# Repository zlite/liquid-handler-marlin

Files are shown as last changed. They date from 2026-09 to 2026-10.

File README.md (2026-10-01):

There have been [many attempts](https://www.hardware-x.com/article/S2468-0672(26)00087-8/fulltext) to modify a cheap Ender 3 printer into a liquid handler using standard syringes, but most suffer from similar problems: too expensive (they often use parts purchased from approved academic vendors, which tend to be way more expensive than their Amazon equivalents), too big, too heavy, too complicated or too imprecise (for example, having no limit switches to accurately home the syringe). 

This is a modern version that improves on all of those dimensions along with adding a useful and easy to use web interface.

Advantages:
- Cheap: less than $250 INCLUDING the computer to control it
- Very precise: it should be good for +/- 10 microliters, repeatably
- Fully automatable via a Web API
- Easy to teach it new tasks, no coding required

BOM:
- Ender 3
- M5Stack Basic
- M5Stack USB module
- Pancake Stepper Motor
- 100m 5m lead screw
- 5mm to 5mm coupler
- 100m MG9 linear rail
- Limit switch
- 100 nf ceramic capaciter

Instructions. When assembling the Ender 3, skip the extruder and filament drive. Although you can re-purpose the stepper motor for our syringe drive, it's a hassle to remove the drive gear and it's bigger and heavier than we need, so I prefer to replace it with the smaller pancake stepper linked above.

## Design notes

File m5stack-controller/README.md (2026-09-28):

# 96-well teaching controller

M5Stack Core Basic + USB Module V1.2 + Ender Liquid Handler R5.
The controller provides a browser page for homing, incremental XYZ jogging,
and recording a standard 8 × 12, 9 mm pitch plate and reservoir.
It does not move automatically at boot. Dry runs leave the syringe stationary;
Home All and the explicit A diagnostics can home/move the syringe.

## Hardware and connection

USB Module switches: SS G5 ON, G0/G13 OFF; INT G35 ON, G34 OFF.
The CH340 Ender adapter (1a86:7523) runs at 250000 baud.
The controller uses USB Host Shield 2.0 with a custom CH340 driver.
Read one endpoint-sized packet at a time: larger reads can receive data then
return NAK without committing the data toggle, losing replies.

At connection, numbered/checksummed commands check firmware identification,
ten complete M114 replies, and acknowledged M400/M84. Motion controls remain
disabled until this passes. No timed-out movement is automatically replayed.
USB reconnect runs the checks again and invalidates session homing.

Open http://dispenser.local or the IP address displayed on the Core.
The network hostname is `dispenser`. The Core screen shows the current task,
connection state, IP address, session homing, last reported XYZ position, and
A limit switch (green **OPEN**, red **TRIGGERED**, yellow **UNKNOWN** when
stale or unavailable). Background switch polling does not replace task status.
It polls `M119` every 200 ms while the command queue is idle. These are
read-only queries and do not move or energize motors. Polling pauses behind
other operations; Marlin cannot service these queries during blocking homing.
Readings expire after one second, and polling can miss shorter pulses.
Use **Read limit switches** in the connection log to query `M119` without
moving. The syringe A-axis switch appears as `a_min`; the diagnostic finishes
with acknowledged motor release.
The web connection section also provides **Read motion settings** (`M503`)
and **Run A-only homing test**. The latter uses `G28 A R0` so XYZ stay put,
records switch/position reports before and after, and ends in `M400`/`M84`.
It requires a fresh OPEN switch reading. Its separate diagnostic log is at
`/api/a-homing-trace` and survives background polling (but not M5 restarts).
These standard G-code diagnostics do not capture brief triggers during homing.
The diagnostic API action `move_a_down_5` makes one 5 mm relative A move toward
home at 1 mm/s using the measured 1600 steps/mm. Because failed homing leaves
an untrustworthy A zero, this test temporarily disables software endstops;
`M120` keeps physical endstops enabled. It restores absolute mode and software
endstops, reports position/switches, and ends with `M400`/`M84`. Run only while
observing clear syringe travel. Physical endstops remain enabled afterward.
The diagnostic API action `hold_a_test` enables all drivers with `M17` without
commanding motion, reads `M119` about every 200 ms for ten seconds, then reads
position and finishes with acknowledged `M400`/`M84` release. The saved
diagnostic log includes timestamped A-switch samples and a trigger count.
Other jobs cannot interleave with the test. This cannot rule out pulses
shorter than the polling interval.
The companion `motion_a_test` uses the same ten-second sampling window after
queueing `G1 A-5 F30` (5 mm downward at 0.5 mm/s, A1600 steps/mm). It retains
physical endstops, temporarily bypasses the untrusted software A zero, and
restores absolute mode/software limits before reporting position and releasing
all motors. An endstop can stop the motion before the sampling window ends;
the samples alone must not be taken as proof of continuous movement.
If Wi-Fi does not connect, join `LiquidHandler-Teach`, password `teachplate96`,
and open http://192.168.4.1. The Core continues trying its configured network.
The page is intended for the local lab network; there is no authentication.

## Teach the deck

1. Secure the plate and reservoir. Clear the homing paths, including below
   the tip. Use the page's Home X/Y and Home Z controls.
2. Jog with 10, 1, or 0.1 mm steps. Raise Z clear of obstacles before XY moves.
3. Align over the **well centers** of A1, A12, and H1, capturing each.
   These define the grid's XY origin, rotation, and spacing.
4. Independently align over H12 and capture the check point. It must agree
   within 1 mm. Recapturing any anchor invalidates the old H12 check.
5. Capture reservoir XYZ at the aspiration location and immersion depth.
   Capture dispense Z at the desired height in a well, then travel Z at a
   height that clears every obstacle. The software checks travel Z exceeds
   the working heights; it cannot detect obstacles or liquid levels.
6. Save setup notes and export the calibration JSON. Once grid and height
   checks pass, the export includes all 96 well XYZ positions.

Each capture waits for M400, reads M114, and waits for M84 acknowledgement
before saving. Each completed jog/homing operation also ends in M400/M114/M84.
All motors release as requested. Released axes can shift without detection;
physically pushing them does not update the reported coordinates. Re-home
if that occurs. Front-panel buttons have no motion-control bindings. The
earlier button-A shortcut was removed after button events during homing
caused a false connection fault and repeated unnumbered release commands.

Points persist in ESP32 NVS across restarts; session homing does not. Recheck
alignment after moving labware or changing the tip. Dispense Z is a single
shared height, assuming a level plate. Nominal center spans are 99 and 63 mm;
geometry checks allow ±3 mm and 3 degrees of squareness. These checks catch
large teaching mistakes, not guarantee pipetting accuracy.

## Syringe calibration

The teach page supports a 1 mL (1,000 µL) syringe and 100 µL doses. Position
the tip over a container and use **Home syringe · empty**. This homes only A,
using the measured 1600 steps/mm; the mechanical endstop must correspond to
an empty syringe. XYZ remain stationary. Jog A upward in 0.1 or 1 mm steps
until the plunger reaches the **300 µL (0.3 mL)** graduation, then **Capture
300 µL**.
Positive A aspirates and negative A dispenses. Observe travel: before capture,
only the firmware's 100 mm A bound is known, not the syringe's physical stroke.
After capture, syringe jogs are limited to the taught full position.

The measured 300 µL travel is captured relative to empty A=0. The full 1 mL
stroke is calculated as measured travel × 10/3; each 100 µL dose uses one third
of measured travel, toward home. For example, a 300 µL capture at A1.2 yields
full A4 and 0.4 mm per dose. Captures whose inferred full stroke exceeds 100 mm
are rejected. Older full-stroke calibrations remain unchanged until recaptured;
JSON records the reference volume and reference A position. A fresh capture
uses the `capture_syringe_300` API action; the old action is rejected so stale
pages cannot silently reinterpret a 1 mL capture as 300 µL. Capture uses M400/M114/M84 and saves only after release
is acknowledged. Homing and jogs also finish with M400/M114/M84. Calibration
persists in NVS and the JSON export's `syringe` object; older saved deck
calibrations load without a syringe calibration. **Clear syringe calibration
only** retains deck teaching and permits reteaching a longer stroke.

Session A homing is required for syringe jogs/capture and is invalidated by
reconnects, faults, unmeasured movement, and A motion/calibration diagnostics.
Released axes can move without detection; re-home if the plunger has shifted.
A saved stroke is a displacement estimate; verify actual delivered liquid volume
before use. The full plate dispensing operation is described below.
The existing route visits eight wells per fill, requiring 800 µL; twelve wells
would require 1,200 µL and cannot use a single 1 mL fill. The wet run uses the same eight-well groups.

## Dry trial

The dry-run control visits the reservoir, then A1 through H1, and repeats for
columns 2 through 12 (12 reservoir visits and 96 distinct wells). It lowers to
the taught reservoir/dispense Z at each location. Z stays at dispense height
between the eight wells of each group; reservoir trips lift to travel height.
Requested XY speed is 500 mm/s and Z speed is 5 mm/s, matching the verified
M203 limits. Existing acceleration limits remain active, so short moves will
not reach the requested maximum. No A moves occur.
The operation is continuous: motors release only at completion or a requested
stop, with acknowledged `M400` / `M84`. One visit is queued at a time. Stop
finishes that visit and then lifts to travel Z; it is not an emergency stop. No job resumes
after a connection fault or reboot. The screen/web status names the group and
current destination; position reports update at each working location and after
the final lift.

All seven points and session XYZ homing are required. Normal H12 tolerance
remains 1 mm. The explicit trial checkbox permits up to 2 mm for that run only;
it does not mark the calibration verified or change saved coordinates. Bounds,
grid geometry, finite coordinates, and travel-height checks still apply.
After firmware installation, re-home from clear paths before starting.

Home All homes X/Y/Z/A, with a separate upward clearance move first. Individual
teaching Home X/Y and Home Z use the same pre-lift. If session Z is referenced,
the lift targets max(current Z, travel Z); otherwise it is a relative lift by
the saved travel height (currently 55 mm), explicitly approved for this machine.
The operator must leave that much free upward travel when Z is unreferenced.
The subsequent G28 uses R0 to avoid a second lift. Missing travel calibration
blocks these home controls. All sequences finish with M400 / M84. Homing speeds
remain the firmware's homing speeds, independent of dry-run feedrates.

## Build

Copy `include/network_secrets.example.h` to `include/network_secrets.h` and
set Wi-Fi credentials (this file is ignored). Without it the hotspot works.

```sh
pio run -d m5stack-controller
pio run -d m5stack-controller -t upload --upload-port /dev/ttyUSB0
g++ -std=c++11 -I m5stack-controller/include m5stack-controller/test/test_teaching.cpp -o /tmp/test-teaching
/tmp/test-teaching
```

Close serial monitors before uploading. Diagnostic serial output is 115200.
The build script selects Core Basic SS5/INT35 in the USB library.

## Validation and limits

Live Ender checks received the full R5 M115 report, ten consecutive complete
M114 replies, and M400/M84 acknowledgements; see
`../artifacts/teaching-ui-boot.log`. Twenty additional HTTP-triggered
position/release jobs passed, and unhomed jog/capture requests were rejected;
see `../artifacts/teaching-http-validation.json`. Geometry/parser tests cover rotation,
malformed replies, skew, and travel limits. Physical homing, jogging, and
labware calibration require operator observation and have not been exercised
by this installation. This supersedes the older TinyUSB probe for teaching.

## Dispense a plate

Use **Dispense full plate · 100 µL/well** after homing X/Y, Z, and A and
calibrating the deck and syringe. No automatic motion occurs on boot or upload.
Wet runs require all seven deck points, the normal 1 mm H12 check, and travel Z no higher than 100 mm. The separate
**Allow H12 error up to 2 mm for this dispensing run only** checkbox permits
up to 2 mm for that run. It does not change saved points or mark the plate
verified; all other validation and homing requirements remain in effect.

The route is twelve groups: A1–H1, A2–H2, … A12–H12. At the taught reservoir
location/depth, move A to empty (0) then aspirate the full 1 mL stroke. Dispense
one tenth of the stroke per well. After eight wells, return to the reservoir,
empty the remaining 200 µL, and refill. After H12, return and empty once more,
then raise to **absolute Z = 100 mm** and finish with M400/M84.
For a 4 mm stroke, full is A4, each dose subtracts 0.4 mm, and each
group ends at A0.8 before purging. Returning to empty uses G1 A0, not G28.

Reservoir trips lift to travel Z before XY moves; the initial lift never lowers
from an already higher Z. Adjacent wells retain dispense Z as in the dry run.
XY requests 500 mm/s, Z 5 mm/s, and A 10 commanded mm/s (F600, ten times the
previous F60). The run sets M203 A10, restoring the measured idle limit M203 A5
at normal completion or an orderly stop. This is not saved to EEPROM. A fault
may interrupt restoration; no recovery motion is issued. Teaching jogs and
homing speeds are unchanged. Steps/mm and saved syringe calibration are not
changed: with the finer screw and A1600, these A units are not physical mm.
Verify actual liquid delivery, missed steps, bubbles and leaks at the higher
speed before a full plate. Acceleration can limit the speedup of short moves.
Motors stay enabled across the
continuous run and release only at the end or a requested stop. Status reports
completed wells. No job automatically resumes after a fault or restart.

**Stop after current location** completes that location (including its fluid
movement), then raises to Z100 and releases. It retains any remaining syringe
fluid and does not purge/refill or visit another well. It is not an emergency
stop. A communication fault instead cancels the sequence and attempts an
ordered motor release without commanding further positioning.

Verify physical liquid delivery and tip priming before dispensing valuable
samples; the controller has no flow or position encoders. The 96 wells receive
9.6 mL nominal total; reservoir liquid must also keep the tip submerged during
the final full-syringe aspiration. Re-home if released axes have shifted.

Host-side sequence test:

```sh
g++ -std=c++11 -I m5stack-controller/include m5stack-controller/test/test_wet_run.cpp -o /tmp/test-wet-run
/tmp/test-wet-run
```

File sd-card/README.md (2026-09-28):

# Ender SD-card plate dispensing

Copy `PLATE100.gcode` to the SD card root and select it from the Ender's
Print from Media / Print from SD menu. The file contains the current full-plate
wet run: 100 uL per well, A1-H1 through A12-H12, with twelve 1 mL fills.
It uses the live controller calibration saved on 2026-09-28 in the adjacent JSON.

Before starting, keep the M5 controller idle and ensure the labware matches
this calibration. Provide at least 75 mm of free upward Z travel and clear
all homing paths. Startup raises Z by 75 mm, then homes XYZ and the syringe;
syringe homing empties any fluid at the homing location, so start empty.
The file performs its own homing on every run.

Travel Z is 75 mm, reservoir is X72 Y158 Z40, and dispense Z is 42 mm.
The calibrated full syringe position is A57.333; A uses 1600 steps per unit.
XY requests 500 mm/s, Z 5 mm/s, and syringe A 10 commanded units/s (F600),
matching the current controller routine. Existing acceleration limits apply.
It purges at the reservoir after the final well, restores the A speed limit
to 5, raises to Z100, and ends with M400 / M84 to release all motors.

This is a fixed calibration snapshot. Export a new job after reteaching.
Keep enough liquid to deliver 9.6 mL while maintaining reservoir immersion.
Sequence checks passed; execution from the physical SD card has not been tested.

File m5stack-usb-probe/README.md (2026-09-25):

# M5Stack Core Basic → Ender USB diagnostic

Hardware communication was demonstrated on 2026-09-24. The Core Basic with
USB Module V1.2 detects the Ender's CH340 (`1a86:7523`) at 250000 baud and
receives Marlin Liquid Handler R5 identification and position replies.
**Long replies currently lose bytes and later replies can stall with the pinned USB library. This is a
communication proof, not a reliable machine-control implementation.**

## Required V1.2 switches

Set these with power off; enable only one route in each switch bank.

| Bank | CH1 | CH2 | CH3 |
| --- | --- | --- | --- |
| SS | OFF (G13) | ON (G5) | OFF (G0) |
| INT | ON (G35) | OFF (G34) | — |

On the user's board/photo, ON is left. INT top G34 is OFF and bottom G35 ON.
SS top G0 is OFF, middle G5 ON, bottom G13 OFF.
The original wrong switch settings prevented USB-chip detection (`0xff`)
and made the screen dark, even with standalone display firmware. Correcting
the switches restored the screen and MAX3421E revision reads (`0x13`).
No EN pin modification is needed for this Basic + V1.2 setup.

## Connections and behavior

- Computer → Core USB-C: upload and diagnostic serial at 115200 baud.
- Module USB-A → Ender USB input; Ender powered normally.
- Module SPI: SCK 18, MOSI 23, MISO 19, CS 5, interrupt 35.
- Ender UART: 250000 baud, 8N1, matching `../marlin/Marlin/Configuration.h`.
- LCD: USB status, scrolling diagnostic text, uptime and received-byte count.
- Button A restarts the diagnostic.
- LCD and USB share one SPI object; SD is disabled.

Each USB attachment sends `M115` (identification), `M114` (position), and
`M119` (endstops), three seconds apart. No motion, homing, heating, or
persistent configuration commands are sent. Computer serial input is not
forwarded. The diagnostic does not implement acknowledgement/retry handling
and its green serial-connected status indicates USB serial mounting, not
validated complete Marlin replies.

## Build / upload

Run from `/home/chris/liquid-handler`:

```sh
pio run -d m5stack-usb-probe -e m5stack
pio run -d m5stack-usb-probe -e m5stack -t upload --upload-port /dev/ttyUSB0
pio device monitor --port /dev/ttyUSB0 --baud 115200
```

The default `m5stack` diagnostic is currently installed. The USB library is
pinned to commit `29544f5c0e118c8bb5f895fccfa8ce9141e8ce1b`. The library is left unmodified; experimental buffering/service changes were
reverted after they failed to establish reliable complete replies.

## Verification and remaining limitation

Build and upload succeed on ESP32-D0WDQ6, 4 MiB flash, USB serial `01BBCF65`.
The host reads MAX3421E revision `0x13` at SPI speeds of 1, 4, 8, and 26 MHz,
then enumerates CH340 and mounts serial at 250000 baud.
The initial switch-corrected test received:

- `FIRMWARE_NAME:Marlin bugfix-2.1.x Liquid Handler R5 (Sep 23 2026 16:11:09)`
- `X:0.00 Y:0.00 Z:0.00 A:0.00 Count X:0 Y:0 Z:0 A:0`, followed by `ok`.
- Endstop response text, with truncation in the longer reply.

Evidence: `../artifacts/m5stack-usb-probe-switches-fixed-2026-09-24.log` and
`../artifacts/m5stack-ender-communication-2026-09-24.log` (final firmware).

Long reply bursts lose bytes; the final retest received a partial M115 reply
but no M114/M119 reply within the capture window. The earlier position/ok
response proves bidirectional communication but not reliable sustained use.
Larger buffers alone did not solve it. The
library's ESP32 interrupt task has a 5 ms delay; shortening/removing it and
trying polling/background service did not yield reliable complete replies.
Those experimental library patches were reverted. Before automated control,
resolve the USB receive issue, verify full replies including acknowledgements
across repeated commands/reconnects, and add an acknowledgement-driven queue.
Motion and dispensing were not tested.

## Standalone screen test

```sh
pio run -d m5stack-usb-probe -e screen-test -t upload --upload-port /dev/ttyUSB0
```

Cycles red/green/blue/white every three seconds, with GPIO32 backlight forced
HIGH, no USB host driver and no SD. Button presses log to serial. The user
confirmed colors with the module removed, and again with it attached after
correcting the switches.

## Original firmware backup

Before the first upload, the complete 4 MiB flash was saved privately to
`../artifacts/m5stack-original-2026-09-24.bin`. Keep it local because it may
contain saved settings/credentials. Restore from the project root with:

```sh
/home/chris/.platformio/penv/bin/esptool --port /dev/ttyUSB0 --baud 460800 write-flash 0 artifacts/m5stack-original-2026-09-24.bin
```

References:
- https://docs.m5stack.com/en/module/USB%20v1.2%20Module
- https://github.com/m5stack/M5-Max3421E-USBShield

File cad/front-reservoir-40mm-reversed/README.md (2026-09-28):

# Corrected front-side reservoir

Corrects the reversed front/back interpretation in `../front-reservoir-40mm/`.
The user's front is the positive-Y end of the plate in source CAD coordinates.
The reservoir stays on the same side (X183), but moves from Y52.26 to Y87.74.
Its +Y edge aligns with the plate's +Y footprint edge at Y112.74.
The nominal plate centre remains (76,70). These are CAD, not machine coordinates.

Reservoir remains 50 x 50 x 40 mm externally, with 2 mm walls and floor.
Capacity is 80.408 mL brim-full. The exterior mark indicates 10 mL, corresponding
to only 4.726 mm liquid depth. Allow extra starting liquid to keep the pickup
submerged while dispensing a full 10 mL. Physical fit and leak tests remain.

The cup geometry is unchanged and can be reused. The deck's locating collar
and its two support links have moved; print the new `LH_deck_four_bolt.stl`.
Plate nest and four mounting holes are unchanged. Print the deck flat.
`LH_reservoir_40mm.stl` is included for convenience; print it upright if needed.
Individual STEP solids and assembly STEP are also included. `LH_deck.stl` is
the intermediate base deck, not the recommended four-bolt version.
Installed cup rim remains Z43.2 above deck underside. Re-teach reservoir XY
and check travel clearance before use. Earlier revisions are preserved.

Rebuild using Python with CadQuery, trimesh, numpy and matplotlib:

```sh
python build_liquid_handler_deck.py
python build_four_bolt_deck.py
python render_deck.py LH_deck_four_bolt
python verify.py
```

Verification records valid single solids, no cup/deck interference, clear bolt
bores, corrected edge alignment, capacity, closed STL meshes, printable bounds
and source/output hashes in `verification.json`.

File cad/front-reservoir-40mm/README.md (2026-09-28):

# Front-aligned reservoir: 40 mm high

Revision of `../front-reservoir-50mm/`, which is preserved unchanged.
Exterior is 50 x 50 x 40 mm, with 2 mm walls and floor. Interior is
46 x 46 x 38 mm, giving 80.408 mL theoretical brim capacity.
The exterior reference notch now marks 10 mL, 6.726 mm above the cup underside.
Calibrate actual printed capacity with measured water.

At 10 mL, liquid is only 4.726 mm deep. Dispensing 10 mL total will require
additional starting liquid to cover residual volume and keep the tip submerged;
the amount depends on tip clearance and pickup geometry. Lowering the walls
does not reduce the flat-bottom reservoir's residual volume.

The footprint, collar, deck, plate position and mounting holes are unchanged.
Cup centre is CAD (183,52.26), with its front at Y27.26 aligned with the nominal
plate footprint front (not the holder's flared lip). Plate centre is (76,70).
Installed cup underside is Z3.2, internal floor Z5.2, and rim Z43.2.
CAD coordinates are not taught machine coordinates. Verify pickup and travel
clearances before operation.

Print `LH_deck_four_bolt.stl` flat and `LH_reservoir_40mm.stl` upright separately.
The previous 50 mm cube's holder can be reused; only the cup needs reprinting.
STEP solids and an assembly STEP are also provided. `LH_deck.stl` is an
intermediate base-deck output, not the recommended four-bolt version.
Use a solid floor, not vase mode; water-test for leaks over a tray.
Physical fit, load and leak testing remain outstanding.

Rebuild with Python, CadQuery, trimesh, numpy and matplotlib:

```sh
python build_liquid_handler_deck.py
python build_four_bolt_deck.py
python render_deck.py LH_deck_four_bolt
python verify.py
```

`verification.json` records runtime versions and source/output hashes, valid
single solids, zero cup/deck overlap, clear mounting bores, front alignment,
capacity, closed meshes and 220 x 220 mm print-area fit.

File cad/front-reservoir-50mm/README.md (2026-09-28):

# Front-aligned 50 mm reservoir

This revision preserves the earlier designs in `../side-reservoir/`.
Reservoir exterior is 50 x 50 x 50 mm. Walls and floor are 2 mm, giving
a 46 x 46 x 48 mm cavity and 101.568 mL theoretical brim capacity.
The shallow exterior mark now indicates 90 mL (44.533 mm above cup bottom),
leaving 5.467 mm headspace. At 100 mL only 0.741 mm headspace remains:
do not treat 100 mL as a practical moving-bed fill level. Calibrate after printing.

The cup sits to the right of the plate. Its exterior front edge aligns with
the nominal plate footprint front edge, NOT the flared holder lip: CAD Y27.26.
Cup centre is (183,52.26), plate centre remains (76,70). Four 4.5 mm mounting
holes remain on the original 170 x 170 mm square. Cup underside sits at Z3.2;
installed rim is Z53.2. All coordinates are CAD datums, not machine positions.
Re-teach reservoir pickup and check raised rim clearance before robot motion.

Print `LH_deck_four_bolt.stl` flat and `LH_reservoir_50mm.stl` upright separately.
Individual STEP solids and an assembly STEP are included. `LH_deck.stl` is
the base builder's intermediate output, not the recommended four-bolt deck.
Use a solid floor, not vase mode; leak-test with water over a tray and test
gently for sloshing. Physical fit, load and leak tests have not been performed.

Rebuild with Python, CadQuery, trimesh, numpy and matplotlib:

```sh
python build_liquid_handler_deck.py
python build_four_bolt_deck.py
python render_deck.py LH_deck_four_bolt
python verify.py
```

Verification checks valid single solids, no cup/deck solid overlap, clear bolt
bores, front-edge alignment, capacity, closed meshes and 220 x 220 mm print-area
fit. `verification.json` records results, runtime versions and source/output hashes.

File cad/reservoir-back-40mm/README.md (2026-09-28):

# Reservoir moved back 40 mm

Revision of `../reservoir-photo-position/LH_deck.stl`, using its CadQuery source.
"Back" follows the existing photograph orientation: CAD +X / upward in the
plan view. Reservoir center moves from (37.12, 151) to (77.12, 151) mm.
The collar, support cross ribs, and its two frame connectors move together.
Plate nest and mounting-feature definitions are retained. Cup dimensions and
capacity are unchanged; the existing reservoir cup can be reused.

- `LH_deck.stl`: revised version of the exact base-deck file requested.
- `LH_deck.step`: matching editable solid.
- `LH_deck_assembly.step`: deck with the cup installed in the new position.
- `reservoir_back_40mm_top.png`: plan view with the old position dashed.
- `LH_deck_four_bolt.*`: companion four-bolt variant, also rebuilt.

The original revision has been preserved. Base-deck bounds are approximately
202.58 × 174.70 × 14.20 mm. Geometry/mesh checks pass: valid connected solids,
watertight positive-volume meshes, no installed cup interference for the
four-bolt assembly, and clear four-bolt bores. A STEP Boolean comparison confirms
all added/removed base-deck material lies outside the plate nest, in the
reservoir-side region (CAD Y > 115 mm). See `verification.json` for details.

Rebuild from this directory using Python with CadQuery, trimesh and matplotlib:

```sh
python build_liquid_handler_deck.py
python build_four_bolt_deck.py
python verify.py
python render_photo_top.py
python render_deck.py LH_deck
```

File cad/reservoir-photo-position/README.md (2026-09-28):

# Reservoir position corrected from the user's photograph

Reference: `/home/chris/Downloads/PXL_20260926_005821466 (1).jpg`.
The black bracket marks the lower-left bay alongside the plate's LONG edge,
not the short-end area used by the two previous revisions. In the photograph,
CAD +X points upward and CAD +Y points leftward.

Cup centre: CAD (37.12,151). Its lower-X edge at X12.12 aligns with the nominal
plate's lower-X edge, corresponding to the bottom/front edge in the photograph.
The lateral bay centre Y151 is retained from the original long-side layout.
The photo establishes the intended bay, not a precision measurement of bracket
position. Plate centre remains (76,70), with unchanged nest and mounting holes.

Reservoir remains 50 x 50 x 40 mm externally, walls/floor 2 mm, cavity
46 x 46 x 38 mm, theoretical brim capacity 80.408 mL. Cup geometry is unchanged
and reusable. The 10 mL mark corresponds to 4.726 mm liquid depth; extra initial
liquid is needed to keep the pickup submerged while dispensing a full 10 mL.

Print the new `LH_deck_four_bolt.stl` flat. The cup STL is included only for
convenience. Individual STEP solids and assembly STEP are provided. The base
`LH_deck.stl` is an intermediate, not the recommended four-bolt version.
Installed rim is Z43.2 above deck underside. CAD coordinates are not machine
coordinates: re-teach reservoir pickup and check clearances before operation.
Previous revisions are preserved. Physical fit/load/leak tests remain outstanding.

Rebuild with Python, CadQuery, trimesh, numpy and matplotlib:

```sh
python build_liquid_handler_deck.py
python build_four_bolt_deck.py
python render_deck.py LH_deck_four_bolt
python render_photo_top.py
python verify.py
```

`verification.json` records single valid solids, no cup/deck interference, clear
mounting bores, front alignment, capacity, closed meshes, printable bounds and
source/output hashes. `photo_orientation_top.png` uses the photograph orientation.

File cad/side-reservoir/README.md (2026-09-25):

# Side-reservoir revision

Based on the original four-bolt deck from
`/home/chris/Documents/Codex/2026-09-21/can/outputs`.
Unmodified source snapshots are in `original/`; existing files were not overwritten.

The reservoir now runs alongside the long edge of the plate, on the +Y side
of the CAD model (formerly the open rear bay). Plate nest geometry, plate
centre (76,70), seating height 3.2 mm and four mounting holes on a 170 mm square
are unchanged. Reservoir centre moves from (183,70) to (105,151).
These are CAD coordinates, not taught machine coordinates.

Reservoir outside dimensions: **104 x 52 x 25 mm**, formerly 52 x 52 x 50 mm.
Walls remain 2 mm. Floor is 1.96 mm rather than 2 mm to preserve the exact
110.592 mL theoretical brim capacity while meeting the exterior size ratios.
Working volume remains 100 mL. The exterior reference mark is 22.7933 mm above
the cup underside. Installed cup rim is 28.2 mm above deck underside, with
the internal floor at 5.16 mm. Actual printed volume requires calibration;
layer rounding will slightly alter these dimensions. Headspace at 100 mL is
only 2.207 mm, so test gently for spills during bed motion.

Print `LH_deck_four_bolt.stl` flat and `LH_reservoir_100mL.stl` upright as
separate parts. Corresponding STEP files are editable solids; the assembly
STEP shows placement and is not a single printable part. The base builder's
`LH_deck.stl` is an intermediate, not the recommended four-bolt deck.
Keep the cup floor solid (about 10 layers at 0.2 mm), not vase mode.
Water-test over a tray before use. No physical fit, leak or load tests performed.
The larger, shallower cup remains removable, with 0.6 mm total collar clearance.
Re-teach reservoir pickup coordinates and verify safe Z clearance before motion.

## Rebuild and validate

Requires Python, CadQuery, trimesh, numpy and matplotlib.

```sh
python build_liquid_handler_deck.py
python build_four_bolt_deck.py
python render_deck.py LH_deck_four_bolt
python verify.py
```

`verification.json` records runtime versions, source/output hashes, calculated
capacity, mesh bounds, watertightness, mounting bore checks and zero cup/deck
solid interference. Preview is `LH_deck_four_bolt_preview.png`.

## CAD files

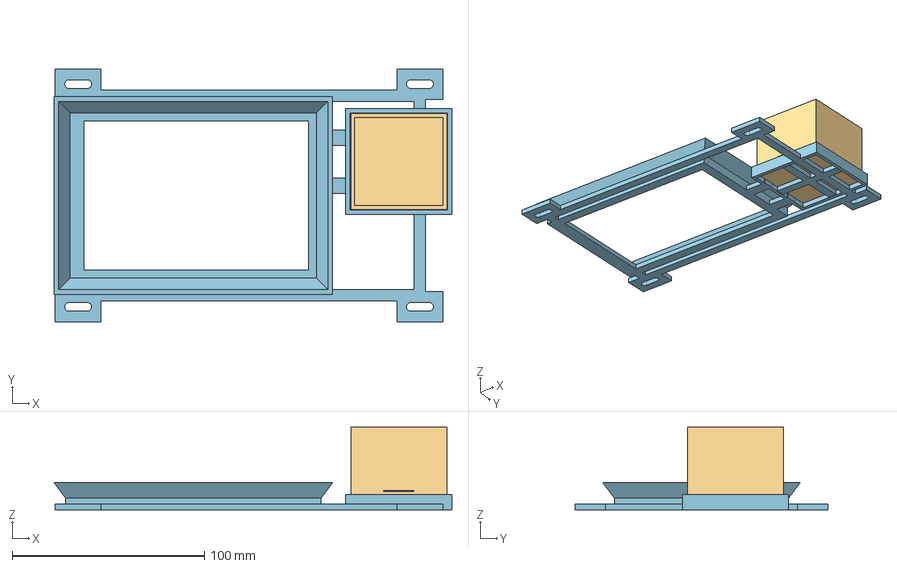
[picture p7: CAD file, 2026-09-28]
cad/front-reservoir-40mm-reversed/LH_deck_assembly.step
207.3 x 132.0 x 43.2 mm
Deck
Removable_reservoir

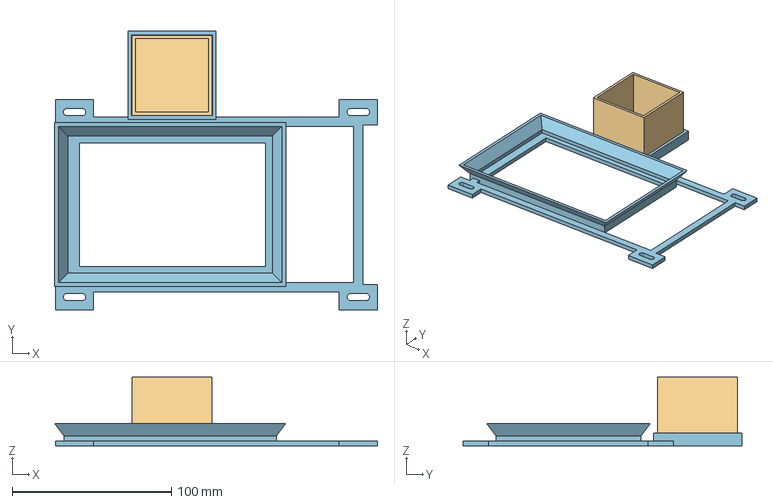
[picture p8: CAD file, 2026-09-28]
cad/reservoir-back-40mm/LH_deck_assembly.step
202.6 x 174.7 x 43.2 mm
Deck
Removable_reservoir

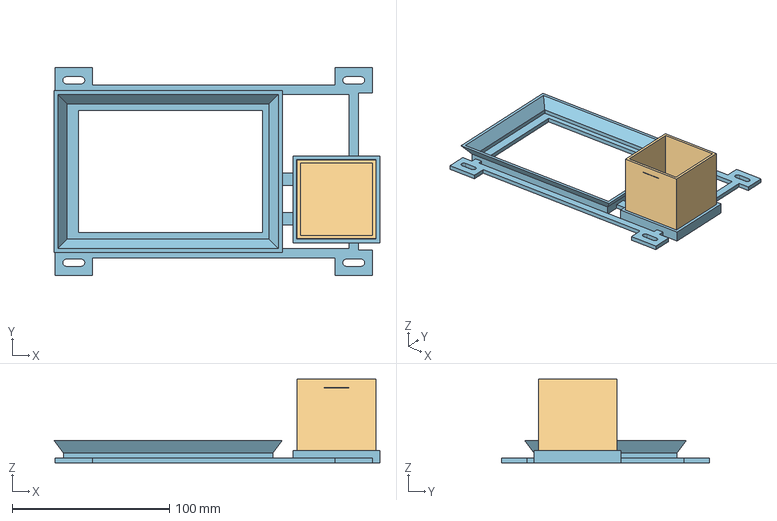
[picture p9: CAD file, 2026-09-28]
cad/front-reservoir-50mm/LH_deck_assembly.step
207.3 x 132.0 x 53.2 mm
Deck
Removable_reservoir

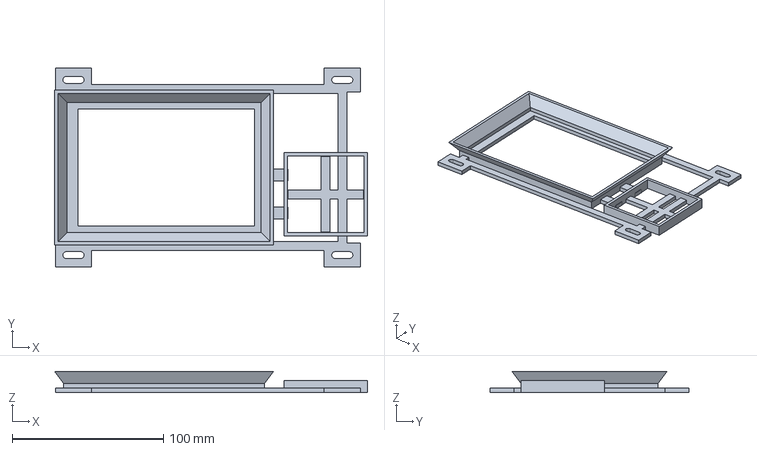
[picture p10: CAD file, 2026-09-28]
cad/front-reservoir-50mm/LH_deck.step
207.3 x 132.0 x 14.2 mm

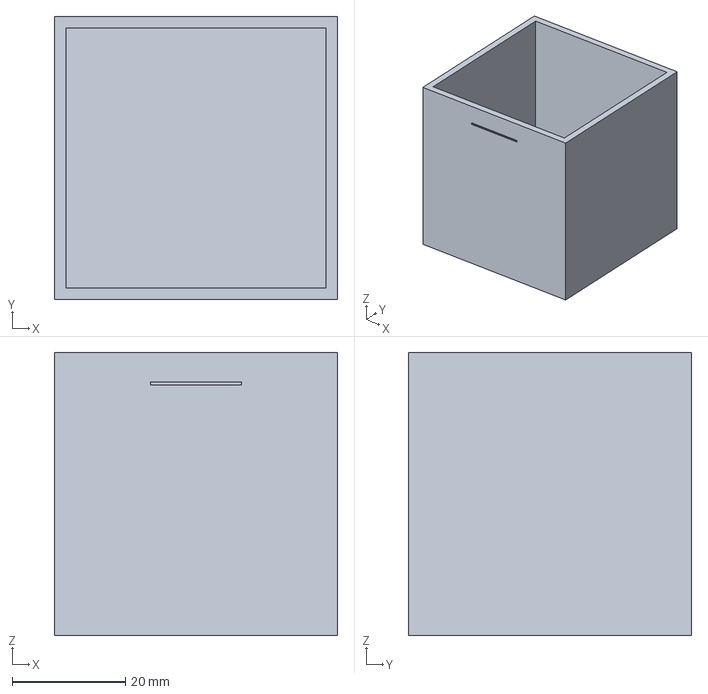
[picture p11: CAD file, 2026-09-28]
cad/front-reservoir-50mm/LH_reservoir_50mm.step
50.0 x 50.0 x 50.0 mm

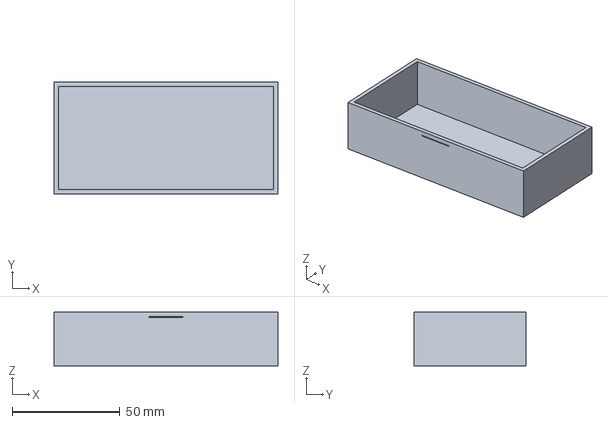
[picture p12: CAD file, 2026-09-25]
cad/side-reservoir/LH_reservoir_100mL.step
104.0 x 52.0 x 25.0 mm

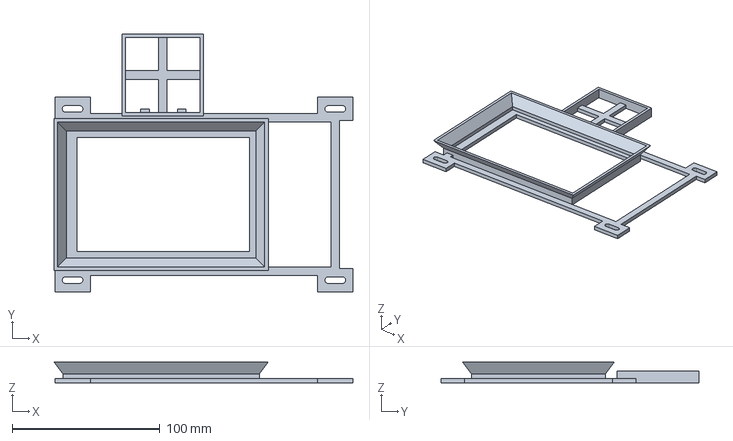
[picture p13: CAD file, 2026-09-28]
cad/reservoir-back-40mm/LH_deck.step
202.6 x 174.7 x 14.2 mm

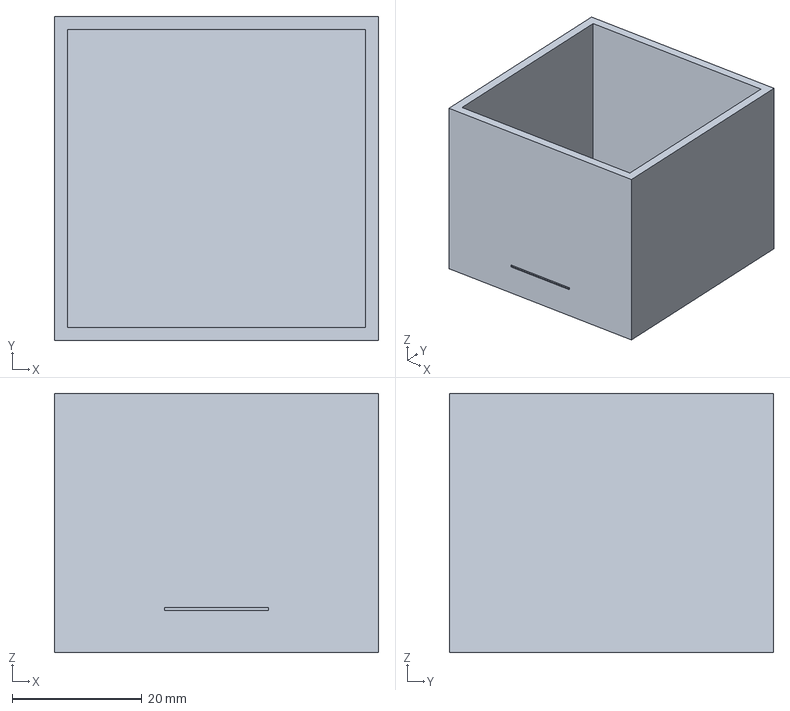
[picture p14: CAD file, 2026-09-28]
cad/front-reservoir-40mm-reversed/LH_reservoir_40mm.step
50.0 x 50.0 x 40.0 mm

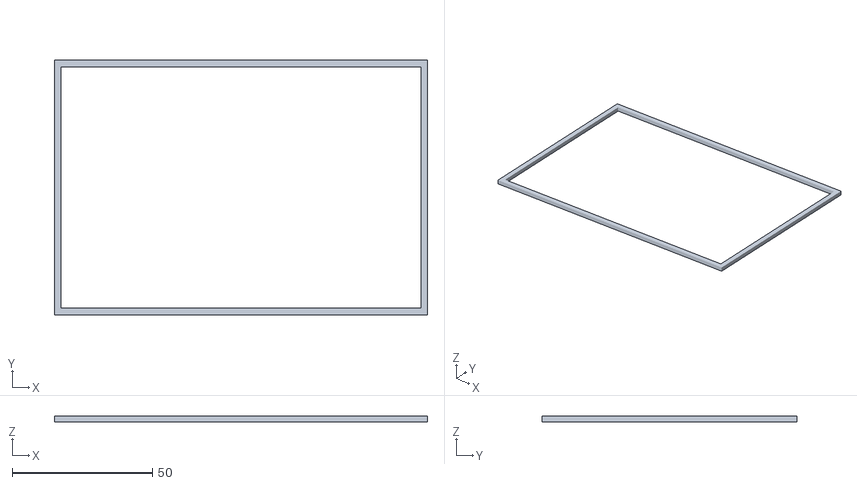
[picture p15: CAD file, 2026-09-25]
cad/front-reservoir-40mm-reversed/LH_optional_plate_fit_gauge.stl
133.2 x 90.9 x 2.00

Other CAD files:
cad/front-reservoir-40mm/LH_deck_assembly.step
cad/reservoir-photo-position/LH_deck_assembly.step
cad/front-reservoir-40mm/LH_deck.step
cad/reservoir-photo-position/LH_deck.step
cad/reservoir-back-40mm/LH_reservoir_40mm.step
cad/front-reservoir-40mm-reversed/LH_deck.step
cad/front-reservoir-40mm/LH_reservoir_40mm.step
cad/reservoir-photo-position/LH_reservoir_40mm.step
cad/front-reservoir-40mm-reversed/LH_deck.stl
cad/front-reservoir-40mm-reversed/LH_deck_four_bolt.step
cad/front-reservoir-40mm-reversed/LH_deck_four_bolt.stl
cad/front-reservoir-40mm-reversed/LH_deck_four_bolt_assembly.step
cad/front-reservoir-40mm-reversed/LH_reservoir_40mm.stl
cad/front-reservoir-40mm/LH_deck.stl
cad/front-reservoir-40mm/LH_deck_four_bolt.step
cad/front-reservoir-40mm/LH_deck_four_bolt.stl
cad/front-reservoir-40mm/LH_deck_four_bolt_assembly.step
cad/front-reservoir-40mm/LH_reservoir_40mm.stl
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

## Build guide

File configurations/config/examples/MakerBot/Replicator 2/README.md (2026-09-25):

# Replicator 2 configuration 

Features:
- Single extruder
- Type K thermocouple
- No heat bed
- Print Area 250mm x 150mm 
- Mightyboard interface (Shift register)
- RGB LED (PCA9632) at addresses 0x62 and 0x70 (all call 0xE0 > 1)

Board: Mightyboard 2, also known as Mightyboard revision G/H
- micro: Atmega1280
- ADS1118 and thermocouples (software SPI)
- Digitpots (software i2C for each at address 0x2F)
- A49888 Motor drivers 

- Flashing: USB or ISP

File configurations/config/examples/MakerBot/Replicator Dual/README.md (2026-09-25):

# Space Issues
## Version Differences
 - The single extruder build enables the `S_CURVE_ACCELERATION` feature due to extra available space.
 - The dual extruder build enables `MARLIN_SMALL_BUILD` to match feature parity with the single extruder build with exception to `S_CURVE_ACCELERATION`.

## Features disabled/enabled to save space.
```
AUTOTEMP
SDCARD_READONLY
NO_SD_AUTOSTART
ARC_SUPPORT
NO_VOLUMETRICS
NO_WORKSPACE_OFFSETS
```

## Fitting S_CURVE_ACCELERATION in the dual build.
Removing `BABYSTEPPING` entirely will allow `S_CURVE_ACCELERATION` to fit on dual extruder builds. However commenting out `DOUBLECLICK_FOR_Z_BABYSTEPPING`, `BABYSTEP_DISPLAY_TOTAL`, and `CONFIGURE_FILAMENT_CHANGE` will fit `S_CURVE_ACCELERATION` without entirely losing `BABYSTEPPING`.

# Flashing
## USB Flashing
MakerBot's Mightyboard Rev E’s are missing capacitor c20. This prevents the board from self resetting to flash over USB. You can try to time pressing the reset button with uploading firmware. I have only ever accomplished this once.

## ICSP Flashing
I find it much easier to flash over the ICSP header using an Arduino and AVR Dude. Adjust settings as necessary such as the port or if you are using a different device to flash. Feel free to reach out to the author of this config in Discord for help.\
`avrdude -v -patmega1280 -cstk500v1 -PCOM4 -b19200 -U flash:w:firmware.hex`

# Printer Information
## Primary Extruder (Dual)
The right nozzle is Extruder 1 (E0) on this printer which will often be confusing as it will be the left temperature on the screen. There are a couple of ways to change this, you can pin swap the pins file. Don’t forget to invert the motor direction. It is possible but not as easy to edit the display order instead.

## Motor Current
The FlashForge Creator Pro example sets current a little higher at .84 for XY&E and .4 for Z. I have matched the MakerBot values from beta.ivc.no of .81 except for Z rounding from .278 to .28. The Z motor will whine more at higher current.

# Modifications

## Part Cooling Fan
If you have added a part cooling fan to the extra mosfet you need to uncomment #define NUM_M106_FANS\
`#define NUM_M106_FANS 1`

You will also need to set the pin definition. This can actually be inserted right below the line you just uncommented.\
`#define FAN0_PIN                  MOSFET_F_PIN`

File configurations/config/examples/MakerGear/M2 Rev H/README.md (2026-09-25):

# MakerGear M2 Rev.H

## Overview
This configuration is built and tested for the MakerGear M2 Revision H. I will note obvious differences in the other revisions to help support them. Some of the original firmware's notes are incorrect, but many of the details are available [here](//makergear.zendesk.com/hc/en-us/articles/360022528292).

## Z Max Homing on Rev F, G, H
Revision E moved the Z end‑stop switch to the bottom (max). For all other revisions set `Z_HOME_DIR` to –1 for Z‑min homing. This is not a common configuration, and certain unexpected behaviors may occur. The primary solution has been to move off the end‑stop by 5mm with `HOMING_BACKOFF_POST_MM`. This mitigates the current Bed Tramming routine moving down by `BED_TRAMMING_Z_HOP`, which defaults to 4mm and does not respect `Z_MAX_POS`.

### Warnings
If the bed is left all the way up, take care when loading filament immediately after powering on the printer. With Z‑Max homing the printer will not lower the bed because it may be at Z‑Max, but it will raise it after. This raise/lower prior to homing can be eliminated with `NO_MOTION_BEFORE_HOMING` at the cost of being able to jog the motors while not homed. Prior revisions have the opposite and/or less of a problem. They will lower the bed (even if all the way down) and raise after.

## Motor / Endstop / Pulley Changes

### Endstops
- Rev F, G, and H are normally closed (hit state `HIGH`).
- Earlier revisions are normally open (hit state `LOW`).

### Z Motor
- Black motors on Rev F, G, and H require `INVERT_Z_DIR true`.
- Black motors on Rev C.1, D, D.1, E, and E.1 should be set to false.
- Silver motors on older revisions should be true.

### Extruder Motor
- `INVERT_E0_DIR false` for Rev F, G, and H.
- Previous revisions are currently unclear but likely set to true.

### Steps Per MM Changes
- Rev G and H use a 16‑tooth pulley specified as 80.1.
- Prior revisions use an 18‑tooth pulley specified as 88.88 or 88.89.
- Silver Z motors are T8×8 specified at 400.
- Black Z motors are Imperial 1/8" specified at 1007.7.

## Hotends
Operating temperatures by version (typical firmware maximum plus overshoot).
- v3a – 220°C
- v3b – 250°C
- v4 – 290°C

## Setting the Distance Between Nozzle and Bed
Most revisions use `M206` to set the nozzle distance from the bed. Z‑Max homed revisions will experience a slightly different workflow from Z‑Min homing. I set the Z‑Max to 210, which on my Rev H places the nozzle just over 1mm from the bed before dialing this in. My printer currently has `M206 Z1.2` set. If I changed `Z_MAX_POS` to 200, I would need to set `M206 Z11.2` instead.

### Basic Guide
1. Power on the printer.
2. Connect Pronterface first; it will reset the printer.
3. Home with `G28`.
4. Move X and Y to the bed center: `G1 F4000 X100 Y150`.
5. Move Z up to 0. Be careful not to go all the way at first.
   - Move very close: `G1 F1800 Z5`.
   - Move the rest of the way: `G1 F100 Z0`.
6. At this point your nozzle probably isn't close to the bed at all. Measure or guess how much closer you need to be.
   - For a first attempt of 1mm, enter `M206 Z1`.
   - Home with `G28` and move back to check the adjustment: `G1 F4000 X100 Y150 Z0`.
   - Adjust again, e.g., 0.2mm closer, by entering the full amount total: `M206 Z1.2`.
   - Repeat the last two steps until you're ready to test print.
7. Save the setting with `M500`.

If the printer's bed is not trammed, tram it now under **Probe & Level**. During the first test print double‑click the screen knob to activate baby stepping. If you find you need further adjustment—for example, you moved +0.05mm away from the bed to make it just right—you can later adjust your `M206` value from 1.2 to 1.25. Don't forget to save.

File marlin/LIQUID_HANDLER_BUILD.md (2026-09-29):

# Liquid Handler firmware build record

## Pinned upstream source

- Repository: `https://github.com/MarlinFirmware/Marlin.git`
- Branch at checkout: `bugfix-2.1.x`
- Commit: `ed5863d337df50652520ecc2d057d8b27749acb6`
- Commit date: `2026-09-22T06:30:09+00:00`
- Commit subject: `[cron] Bump distribution date (2026-09-22)`

The commit hash, rather than the moving branch name, is the reproducible source
identifier. To recreate the source checkout:

```sh
git clone https://github.com/MarlinFirmware/Marlin.git marlin
cd marlin
git checkout --detach ed5863d337df50652520ecc2d057d8b27749acb6
```

Apply the tracked changes to `Marlin/Configuration.h` and
`Marlin/Configuration_adv.h` and `Marlin/Version.h`, then build with:

```sh
buildroot/bin/mftest -a -n1
```

## Hardware assumptions

- Creality V4.2.2 with GD32F303RET6, selected as
  `BOARD_CREALITY_V422_GD32_MFL`.
- H8 / HR4988 fixed-step drivers are configured with A4988-compatible timing.
- Stock Ender 3 X/Y/Z mechanics: 235 x 235 x 250 mm.
- Stock Creality 12864 rotary-encoder LCD (`CR10_STOCKDISPLAY`).
- No extruders, hotends, temperature sensors, or heater outputs.
- The original fan output remains available with the board-required software
  PWM; it is not used as a heater output.
- E0 stepper socket is auto-assigned to the fourth linear axis, exposed in
  G-code as `A`.
- R6 A-axis calibration: 3200 steps/mm for the new 1 mm pitch screw, calculated
  as 1600 * 2 / 1 from the user-confirmed old 2 mm and new 1 mm pitches.
  This assumes equal numbers of starts and unchanged motor/driver/gearing.
  The new value has not yet been verified by physical measurement.
- Historical A-axis calibration: 1600 steps/mm, measured on 2026-09-25. Repeated complete
  upward moves of 3200 pulses each produced 2 mm of measured travel. This
  supersedes the earlier 320 steps/mm estimate and the 3200 steps/mm value
  found in EEPROM. Downward moves that stopped early were not used to calibrate.
  A commanded 2 mm upward move at A1600 was confirmed physically. Saved with
  M500 and reloaded with M501 on 2026-09-25; M503 confirmed A1600 after reload.
  See `../artifacts/direct_ender_diagnostic.log` (save-and-reload-a1600).
- A travel is provisionally 0-100 mm, homing toward minimum at 1 mm/s.
- A-min switch uses PB1 (connector silkscreen OUT) and GND, internal pull-up,
  triggered HIGH. The center IN pin is PB0 and must not be used for this switch.
- R5 sets INVERT_Z_DIR=true and INVERT_I_DIR=false following explicit physical
  tests that positive Z and A jogs in the direction-fix build moved down/toward
  home. Confirm positive jogs now move up/away before homing. HOME_DIR remains -1.

## Mandatory checks before homing or dispensing

1. With motors disabled, issue `M119` and confirm A reports open away from the
   switch and triggered when the switch is pressed. Reverse
   `I_MIN_ENDSTOP_HIT_STATE` if necessary.
2. Jog A a very small distance away from the switch. If motion is reversed,
   change `INVERT_I_DIR` before attempting `G28 A`.
3. Confirm the actual collision-free syringe travel. Reduce `I_MAX_POS` if it
   is less than 100 mm.
4. Calibrate plunger displacement gravimetrically before relying on volume.

No firmware should be flashed until the build succeeds and these assumptions
have been reviewed.

## Historical R5 build (before the 1600 steps/mm correction)

- Environment: `GD32F303RE_creality_mfl`
- Result: success
- RAM: 8,880 / 65,536 bytes (13.5%)
- Flash: 125,560 / 495,616 bytes (25.3%)
- Binary size: 125,956 bytes
- Startup splash revision: `Biokea R5` (also included in M115).
- Machine name: `Biokea R5`; normal status message: `Biokea R5 Ready.`
- Stable artifact:
  `../artifacts/Biokea-R5.bin`
- SHA-256:
  `2276a95c4f06053e8e4f2dd276f99fedfbee0bbdf43fc9ffc7e58f39efebbf9f`
- ELF vector-table address: `0x08007000` (the required Creality bootloader
  offset)
- Embedded M115 identity: `MACHINE_TYPE:Biokea R5`,
  `EXTRUDER_COUNT:0`, `AXIS_COUNT:4`

The binary has been built and inspected, but not flashed.

For the historical 1600 steps/mm calibration revision, either reset all persisted settings
to the compiled defaults with `M502` followed by `M500`, or update only the A
axis with `M92 A1600` followed by `M500`. Use `M503` to confirm the active value.
The historical binary above predates this correction; changing EEPROM through
G-code does not require reflashing that binary.

## R6: 1 mm pitch syringe screw (2026-09-28)

- Build command: `pio run -e GD32F303RE_creality_mfl` from `marlin/`.
- Result: success; RAM 8,880 / 65,536 bytes, flash 125,560 / 495,616 bytes.
- Artifact: `../artifacts/Biokea-R6-A3200.bin` (125,956 bytes).
- SHA-256: `ce92f445f20447e1bfb9e2d2751ea4ebe9ca8ec205039f403e4ad2d62d31b172`.
- Identity: `Biokea R6`; default XYZ/A steps/mm: 80, 80, 400, 3200.
- Binary inspection verified the compiled calibration, R6 identity, and reset
  vector within the image linked at the Creality bootloader offset 0x08007000.
- Built and inspected only; not flashed or motion-tested.

Copy the binary to the printer SD card root with a filename distinct from the
previous flash, then boot the printer with that card to install it. Existing
EEPROM settings override compiled defaults. With the machine idle, run
`../artifacts/SET_A3200.gcode` after flashing, or send its commands through the
trusted controller job queue. It sets only A steps/mm, saves with M500, reports
with M503, and ends with M400 / M84. Confirm A3200 in the report and Biokea R6
with M115. Re-home before trusting any coordinates.

Compatibility: `m5stack-controller/src/main.cpp` and `sd-card/PLATE100.gcode`
still explicitly send M92 A1600. Those existing workflows retain their old
coordinate scale and will override R6's A3200 setting at runtime. Before using
them with the new physical-mm scale, update the override and re-teach syringe
positions / regenerate the SD job together. Do not simply replace M92 in an
existing dispensing job while keeping its A coordinates: doubling steps/mm
would double its commanded physical travel. The saved A57.333 full position
was captured at A1600 on the finer screw and is not valid unchanged at A3200.
Controller firmware and historical SD jobs were not modified by this build.

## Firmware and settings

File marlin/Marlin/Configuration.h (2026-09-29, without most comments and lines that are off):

#pragma once
#define CONFIGURATION_H_VERSION 02010300
#define STRING_CONFIG_H_AUTHOR "(Liquid Handler conversion)" // Original author or contributor.
#define CUSTOM_VERSION_FILE Version.h // Path from the root directory (no quotes)
  #define MOTHERBOARD BOARD_CREALITY_V422_GD32_MFL
#define I_MIN_PIN PB1
#define HEATER_0_PIN   -1
#define HEATER_BED_PIN -1
#define SERIAL_PORT 0
#define BAUDRATE 250000
#define CUSTOM_MACHINE_NAME "Biokea R6"
#define X_DRIVER_TYPE  A4988
#define Y_DRIVER_TYPE  A4988
#define Z_DRIVER_TYPE  A4988
#define I_DRIVER_TYPE  A4988
#define E0_DRIVER_TYPE A4988
  #define AXIS4_NAME 'A' // :['A', 'B', 'C', 'U', 'V', 'W']
#define EXTRUDERS 0
#define DEFAULT_NOMINAL_FILAMENT_DIA 1.75
#define TEMP_SENSOR_0 0
#define TEMP_SENSOR_1 0
#define TEMP_SENSOR_2 0
#define TEMP_SENSOR_3 0
#define TEMP_SENSOR_4 0
#define TEMP_SENSOR_5 0
#define TEMP_SENSOR_6 0
#define TEMP_SENSOR_7 0
#define TEMP_SENSOR_BED 0
#define TEMP_SENSOR_PROBE 0
#define TEMP_SENSOR_CHAMBER 0
#define TEMP_SENSOR_COOLER 0
#define TEMP_SENSOR_BOARD 0
#define TEMP_SENSOR_SOC 0
#define TEMP_SENSOR_REDUNDANT 0
#define DUMMY_THERMISTOR_998_VALUE  25
#define DUMMY_THERMISTOR_999_VALUE 100
#if TEMP_SENSOR_IS_MAX_TC(0)
  #define MAX31865_SENSOR_OHMS_0      100 // (Ω) Typically 100 or 1000 (PT100 or PT1000)
  #define MAX31865_CALIBRATION_OHMS_0 430 // (Ω) Typically 430 for Adafruit PT100; 4300 for Adafruit PT1000
#endif
#if TEMP_SENSOR_IS_MAX_TC(1)
  #define MAX31865_SENSOR_OHMS_1      100
  #define MAX31865_CALIBRATION_OHMS_1 430
#endif
#if TEMP_SENSOR_IS_MAX_TC(2)
  #define MAX31865_SENSOR_OHMS_2      100
  #define MAX31865_CALIBRATION_OHMS_2 430
#endif
#if TEMP_SENSOR_IS_MAX_TC(BED)
  #define MAX31865_SENSOR_OHMS_BED      100
  #define MAX31865_CALIBRATION_OHMS_BED 430
#endif
#if HAS_E_TEMP_SENSOR
  #define TEMP_RESIDENCY_TIME         10  // (seconds) Time to wait for hotend to "settle" in M109
  #define TEMP_WINDOW                  1  // (°C) Temperature proximity for the "temperature reached" timer
  #define TEMP_HYSTERESIS              3  // (°C) Temperature proximity considered "close enough" to the target
#endif
#if TEMP_SENSOR_BED
  #define TEMP_BED_RESIDENCY_TIME     10  // (seconds) Time to wait for bed to "settle" in M190
  #define TEMP_BED_WINDOW              1  // (°C) Temperature proximity for the "temperature reached" timer
  #define TEMP_BED_HYSTERESIS          3  // (°C) Temperature proximity considered "close enough" to the target
#endif
#if TEMP_SENSOR_CHAMBER
  #define TEMP_CHAMBER_RESIDENCY_TIME 10  // (seconds) Time to wait for chamber to "settle" in M191
  #define TEMP_CHAMBER_WINDOW          1  // (°C) Temperature proximity for the "temperature reached" timer
  #define TEMP_CHAMBER_HYSTERESIS      3  // (°C) Temperature proximity considered "close enough" to the target
#endif
#if TEMP_SENSOR_REDUNDANT
  #define TEMP_SENSOR_REDUNDANT_SOURCE    E1  // The sensor that will provide the redundant reading.
  #define TEMP_SENSOR_REDUNDANT_TARGET    E0  // The sensor that we are providing a redundant reading for.
  #define TEMP_SENSOR_REDUNDANT_MAX_DIFF  10  // (°C) Temperature difference that will trigger a print abort.
#endif
#define HEATER_0_MINTEMP   5
#define HEATER_1_MINTEMP   5
#define HEATER_2_MINTEMP   5
#define HEATER_3_MINTEMP   5
#define HEATER_4_MINTEMP   5
#define HEATER_5_MINTEMP   5
#define HEATER_6_MINTEMP   5
#define HEATER_7_MINTEMP   5
#define BED_MINTEMP        5
#define CHAMBER_MINTEMP    5
#define HEATER_0_MAXTEMP 275
#define HEATER_1_MAXTEMP 275
#define HEATER_2_MAXTEMP 275
#define HEATER_3_MAXTEMP 275
#define HEATER_4_MAXTEMP 275
#define HEATER_5_MAXTEMP 275
#define HEATER_6_MAXTEMP 275
#define HEATER_7_MAXTEMP 275
#define BED_MAXTEMP      150
#define CHAMBER_MAXTEMP  60
#define HOTEND_OVERSHOOT 15   // (°C) Forbid temperatures over MAXTEMP - OVERSHOOT
#define BED_OVERSHOOT    10   // (°C) Forbid temperatures over MAXTEMP - OVERSHOOT
#define COOLER_OVERSHOOT  2   // (°C) Forbid temperatures closer than OVERSHOOT
#define PIDTEMP           // See the PID Tuning Guide at https://reprap.org/wiki/PID_Tuning
#define PID_MAX  255      // Limit hotend current while PID is active (see PID_FUNCTIONAL_RANGE below); 255=full current
#define PID_K1     0.95   // Smoothing factor within any PID loop
    #define DEFAULT_KP  22.20
    #define DEFAULT_KI   1.08
    #define DEFAULT_KD 114.00
#define MAX_BED_POWER 255 // limits duty cycle to bed; 255=full current
#define MAX_CHAMBER_POWER 255 // limits duty cycle to chamber heater; 255=full current
  #define PID_FUNCTIONAL_RANGE 20 // If the temperature difference between the target temperature and the actual temperature
#define PREVENT_COLD_EXTRUSION
#define EXTRUDE_MINTEMP 170
#define PREVENT_LENGTHY_EXTRUDE
#define EXTRUDE_MAXLENGTH 200
#define THERMAL_PROTECTION_HOTENDS // Enable thermal protection for all extruders
#define THERMAL_PROTECTION_BED     // Enable thermal protection for the heated bed
#define THERMAL_PROTECTION_CHAMBER // Enable thermal protection for the heated chamber
#define THERMAL_PROTECTION_COOLER  // Enable thermal protection for the laser cooling
#define ENDSTOPPULLUPS
#define X_MIN_ENDSTOP_HIT_STATE HIGH
#define X_MAX_ENDSTOP_HIT_STATE HIGH
#define Y_MIN_ENDSTOP_HIT_STATE HIGH
#define Y_MAX_ENDSTOP_HIT_STATE HIGH
#define Z_MIN_ENDSTOP_HIT_STATE HIGH
#define Z_MAX_ENDSTOP_HIT_STATE HIGH
#define I_MIN_ENDSTOP_HIT_STATE HIGH
#define I_MAX_ENDSTOP_HIT_STATE HIGH
#define J_MIN_ENDSTOP_HIT_STATE HIGH
#define J_MAX_ENDSTOP_HIT_STATE HIGH
#define K_MIN_ENDSTOP_HIT_STATE HIGH
#define K_MAX_ENDSTOP_HIT_STATE HIGH
#define U_MIN_ENDSTOP_HIT_STATE HIGH
#define U_MAX_ENDSTOP_HIT_STATE HIGH
#define V_MIN_ENDSTOP_HIT_STATE HIGH
#define V_MAX_ENDSTOP_HIT_STATE HIGH
#define W_MIN_ENDSTOP_HIT_STATE HIGH
#define W_MAX_ENDSTOP_HIT_STATE HIGH
#define Z_MIN_PROBE_ENDSTOP_HIT_STATE HIGH
#define DEFAULT_AXIS_STEPS_PER_UNIT   { 80, 80, 400, 3200 }
#define EDITABLE_STEPS_PER_UNIT
#define DEFAULT_MAX_FEEDRATE          { 500, 500, 5, 5 }
#define DEFAULT_MAX_ACCELERATION      { 500, 500, 100, 50 }
#define DEFAULT_ACCELERATION           500    // X, Y, Z and A acceleration for coordinated moves
#define DEFAULT_RETRACT_ACCELERATION   500    // Unused with EXTRUDERS=0
#define DEFAULT_TRAVEL_ACCELERATION    500    // X, Y, Z and A acceleration for travel moves
  #define JUNCTION_DEVIATION_MM 0.013 // (mm) Distance from real junction edge
  #define JD_HANDLE_SMALL_SEGMENTS    // Use curvature estimation instead of just the junction angle
#define Z_MIN_PROBE_USES_Z_MIN_ENDSTOP_PIN
#define NOZZLE_TO_PROBE_OFFSET { 10, 10, 0 } // (mm) X, Y, Z distance from Nozzle tip to Probe trigger-point
#define PROBING_TOOL 0
#define PROBING_MARGIN 10
#define XY_PROBE_FEEDRATE    (133*60) // (mm/min)
#define Z_PROBE_FEEDRATE_FAST  (4*60) // (mm/min)
#define Z_PROBE_FEEDRATE_SLOW (Z_PROBE_FEEDRATE_FAST / 2) // (mm/min)
#define Z_CLEARANCE_DEPLOY_PROBE   10 // (mm) Z Clearance for Deploy/Stow
#define Z_CLEARANCE_BETWEEN_PROBES  5 // (mm) Z Clearance between probe points
#define Z_CLEARANCE_MULTI_PROBE     5 // (mm) Z Clearance between multiple probes
#define Z_PROBE_ERROR_TOLERANCE     3 // (mm) Tolerance for early trigger (<= -probe.offset.z + ZPET)
#define Z_PROBE_LOW_POINT          -2 // (mm) Farthest distance below the trigger-point to go before stopping
#define X_ENABLE_ON LOW
#define Y_ENABLE_ON LOW
#define Z_ENABLE_ON LOW
#define E_ENABLE_ON LOW // For all extruders
#define I_ENABLE_ON LOW
#define DISABLE_OTHER_EXTRUDERS   // Keep only the active extruder enabled
#define INVERT_X_DIR false
#define INVERT_Y_DIR false
#define INVERT_Z_DIR true
#define INVERT_I_DIR false
#define INVERT_E0_DIR false
#define INVERT_E1_DIR false
#define INVERT_E2_DIR false
#define INVERT_E3_DIR false
#define INVERT_E4_DIR false
#define INVERT_E5_DIR false
#define INVERT_E6_DIR false
#define INVERT_E7_DIR false
#define X_HOME_DIR -1
#define Y_HOME_DIR -1
#define Z_HOME_DIR -1
#define I_HOME_DIR -1
#define X_BED_SIZE 235
#define Y_BED_SIZE 235
#define X_MIN_POS 0
#define Y_MIN_POS 0
#define Z_MIN_POS 0
#define X_MAX_POS X_BED_SIZE
#define Y_MAX_POS Y_BED_SIZE
#define Z_MAX_POS 250
#define I_MIN_POS 0
#define I_MAX_POS 100
#define MIN_SOFTWARE_ENDSTOPS
  #define MIN_SOFTWARE_ENDSTOP_X
  #define MIN_SOFTWARE_ENDSTOP_Y
  #define MIN_SOFTWARE_ENDSTOP_Z
  #define MIN_SOFTWARE_ENDSTOP_I
  #define MIN_SOFTWARE_ENDSTOP_J
  #define MIN_SOFTWARE_ENDSTOP_K
  #define MIN_SOFTWARE_ENDSTOP_U
  #define MIN_SOFTWARE_ENDSTOP_V
  #define MIN_SOFTWARE_ENDSTOP_W
#define MAX_SOFTWARE_ENDSTOPS
  #define MAX_SOFTWARE_ENDSTOP_X
  #define MAX_SOFTWARE_ENDSTOP_Y
  #define MAX_SOFTWARE_ENDSTOP_Z
  #define MAX_SOFTWARE_ENDSTOP_I
  #define MAX_SOFTWARE_ENDSTOP_J
  #define MAX_SOFTWARE_ENDSTOP_K
  #define MAX_SOFTWARE_ENDSTOP_U
  #define MAX_SOFTWARE_ENDSTOP_V
  #define MAX_SOFTWARE_ENDSTOP_W
#define HOMING_FEEDRATE_MM_M { (20*60), (20*60), (4*60), (1*60) }
#define VALIDATE_HOMING_ENDSTOPS
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

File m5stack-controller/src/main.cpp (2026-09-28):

#include <M5Stack.h>
#include <WiFi.h>
#include <WebServer.h>
#include <ESPmDNS.h>
#include <Preferences.h>
#include <ArduinoJson.h>
#include "ch340_host.h"
#include "teaching.h"
#include "dry_run.h"
#include "wet_run.h"
#include "web_page.h"
#if __has_include("network_secrets.h")
#include "network_secrets.h"
#else
constexpr char WIFI_SSID[]="";
constexpr char WIFI_PASSWORD[]="";
#endif

USB usb;
Ch340Host ender(usb);
WebServer web(80);
Preferences preferences;
constexpr char HOSTNAME[]="dispenser";
constexpr char A_CALIBRATION[]="M92 A1600";
const char *pointNames[]={"a1","a12","h1","h12","reservoir","dispense","travel"};
Position points[7],position,candidate;
bool present[7]={},havePosition=false,ready=false,connected=false,xyHomed=false,zHomed=false;
bool aHomed=false;
float syringeFull=NAN,syringeReferenceUl=1000.0f;
bool busy=false,awaiting=false,positionSeen=false,identitySeen=false,saved=false,mdns=false;
String calName="96-well plate",notes,message="Starting USB",logText,job;
String commands[24];unsigned commandCount=0,commandIndex=0,lineNumber=0,capabilities=0;
int captureIndex=-1;
uint32_t mountedAt=0,sentAt=0,lastRX=0,lastDraw=0,lastWeb=0;
char inputLine[512];size_t inputLength=0;
bool droppingLine=false,hostOK=false;
bool aLimitKnown=false,aLimitTriggered=false;
int pendingALimit=-1;
uint32_t aLimitAt=0,lastLimitPoll=0,aLimitSamples=0;
constexpr uint32_t LIMIT_POLL_MS=200,LIMIT_STALE_MS=1000;
const char *LIMIT_MONITOR="Monitor A switch";
const char *HOLD_TEST="Stationary motor test";
const char *MOTION_TEST="Moving motor test";
uint32_t holdStartedAt=0,holdLastPoll=0,holdSamples=0,holdTriggers=0;
bool samplingCommand(){return (job==HOLD_TEST&&commandIndex==4)||(job==MOTION_TEST&&commandIndex==9);}
String aHomingTrace;
bool dryRunning=false,dryStop=false;
unsigned dryVisit=0;
bool wetRunning=false,wetStop=false;
unsigned wetVisit=0,wetWellsDone=0;

bool aLimitFresh(){return connected&&ready&&aLimitKnown&&millis()-aLimitAt<LIMIT_STALE_MS;}

void logMessage(const String &s){
  Serial.println(s);
  logText+=s+"\n";
  if(logText.length()>3000)logText.remove(0,logText.length()-3000);
  if(busy&&(job=="Diagnose A homing"||job=="Read motion settings"||job=="Set A calibration"||job=="Move A down 5 mm"||job==HOLD_TEST||job==MOTION_TEST)){
    aHomingTrace+=s+"\n";
    if(aHomingTrace.length()>12000)aHomingTrace.remove(0,aHomingTrace.length()-12000);
  }
}
void serializePosition(JsonObject o,const Position &p){o["x"]=p.x;o["y"]=p.y;o["z"]=p.z;o["a"]=p.a;}
bool geometryOK(){return present[0]&&present[1]&&present[2]&&validPlate(points[0],points[1],points[2]);}
float checkError(){return distanceXY(wellPosition(points[0],points[1],points[2],7,11),points[3]);}
bool plateVerified(){return geometryOK()&&present[3]&&checkError()<=1.0f;}
bool heightsOK(){return present[4]&&present[5]&&present[6]&&points[6].z>points[4].z&&points[6].z>points[5].z;}
void calibration(JsonDocument &d){
  d["schema"]=1;d["name"]=calName;d["notes"]=notes;d["rows"]=8;d["columns"]=12;d["nominalPitchMm"]=9;
  d["units"]="mm";d["plateVerified"]=plateVerified();d["heightsValid"]=heightsOK();
  auto syringe=d["syringe"].to<JsonObject>();
  syringe["capacityUl"]=SYRINGE_CAPACITY_UL;syringe["doseUl"]=SYRINGE_DOSE_UL;
  syringe["emptyA"]=0;syringe["calibrated"]=validSyringeFull(syringeFull);
  if(validSyringeFull(syringeFull)){
    syringe["fullA"]=syringeFull;syringe["strokeMm"]=syringeFull;
    syringe["doseTravelMm"]=syringeDoseTravel(syringeFull);
    syringe["referenceUl"]=syringeReferenceUl;
    syringe["referenceA"]=syringeFull*syringeReferenceUl/SYRINGE_CAPACITY_UL;
  }
  auto ps=d["points"].to<JsonObject>();
  for(unsigned i=0;i<7;i++)if(present[i])serializePosition(ps[pointNames[i]].to<JsonObject>(),points[i]);
  if(plateVerified()&&heightsOK()){
    auto wells=d["wells"].to<JsonObject>();
    for(unsigned r=0;r<8;r++)for(unsigned c=0;c<12;c++){
      Position p=wellPosition(points[0],points[1],points[2],r,c);p.z=points[5].z;
      String name=String(char('A'+r))+String(c+1);
      auto w=wells[name].to<JsonObject>();w["x"]=p.x;w["y"]=p.y;w["z"]=p.z;
    }
  }
}
bool persist(){
  JsonDocument d;calibration(d);d.remove("wells");String s;serializeJson(d,s);
  saved=preferences.putString("calibration",s)==s.length();return saved;
}
void load(){
  String s=preferences.getString("calibration","");if(s.isEmpty())return;
  JsonDocument d;if(deserializeJson(d,s)||d["schema"].as<int>()!=1)return;
  calName=d["name"]|"96-well plate";notes=d["notes"]|"";
  for(unsigned i=0;i<7;i++){
    JsonObject p=d["points"][pointNames[i]].as<JsonObject>();
    if(!p["x"].is<float>()||!p["y"].is<float>()||!p["z"].is<float>()||!p["a"].is<float>())continue;
    Position v{p["x"].as<float>(),p["y"].as<float>(),p["z"].as<float>(),p["a"].as<float>()};
    if(inside(v)&&std::isfinite(v.a)){points[i]=v;present[i]=true;}
  }
  float full=d["syringe"]["fullA"]|NAN;
  if(validSyringeFull(full)){
    syringeFull=full;
    // Existing full-stroke calibrations retain their original meaning.
    syringeReferenceUl=d["syringe"]["referenceUl"]|1000.0f;
    if(syringeReferenceUl!=300.0f&&syringeReferenceUl!=1000.0f)syringeReferenceUl=1000.0f;
  }
  saved=true;
}
void fail(const String &reason){
  if(message.startsWith("Connection fault:"))return;
  dryRunning=wetRunning=false;
  message="Connection fault: "+reason+". Reconnect USB to recheck.";
  logMessage(message);busy=awaiting=ready=false;xyHomed=zHomed=aHomed=false;havePosition=false;
  aLimitKnown=false;
  // Best effort ordered release, never replay a timed-out movement.
  if(connected){ender.write((job=="Move A down 5 mm"||job==MOTION_TEST)?"M400\nG90\nM211 S1\nM84\n":"M400\nM84\n");}
}
void beginJob(const String &name,std::initializer_list<String> sequence,int capture=-1){
  job=name;captureIndex=capture;commandCount=0;commandIndex=0;busy=true;awaiting=false;
  for(const auto &s:sequence)commands[commandCount++]=s;
  if(name!=LIMIT_MONITOR){message=name;logMessage("Operation: "+name);}
}
void nextDryVisit(){
  Position p=dryRunTarget(points,dryVisit);
  String label=dryVisit%9?String(char('A'+dryVisit%9-1))+String(dryVisit/9+1):"Reservoir";
  String name="Dry run "+String(dryVisit/9+1)+"/12: "+label;
  // Lift only across the reservoir/plate boundary. Adjacent wells share Z.
  if(dryRunNeedsClearance(dryVisit)){
    beginJob(name,{"G21","G90","M211 S1",
      "G1 Z"+String(points[6].z,3)+" F300","M400",
      "G1 X"+String(p.x,3)+" Y"+String(p.y,3)+" F30000","M400",
      "G1 Z"+String(p.z,3)+" F300","M400","M114"});
  }else{
    beginJob(name,{"G21","G90",
      "G1 X"+String(p.x,3)+" Y"+String(p.y,3)+" F30000","M400","M114"});
  }
}
void nextWetVisit(){
  String label;
  if(wetVisit==WET_PARK_VISIT)label=wetStop?"stopped; parking Z100":"finished; parking Z100";
  else if(wetVisit==WET_PURGE_VISIT)label="final reservoir purge";
  else if(wetVisit%9==0)label="group "+String(wetVisit/9+1)+"/12: purge and fill 1 mL";
  else label=String(char('A'+wetVisit%9-1))+String(wetVisit/9+1)+": dispense 100 uL";
  WetBatch batch=wetRunBatch(points,syringeFull,wetVisit,position.z);
  beginJob("Dispense "+label,{});
  for(unsigned i=0;i<batch.count;i++)commands[commandCount++]=batch.commands[i];
}
void startCheck(){
  lineNumber=0;identitySeen=false;capabilities=0;
  beginJob("Checking Marlin replies",{"M110 N0","M115","M114","M114","M114","M114","M114","M114","M114","M114","M114","M114","M400","M84"});
}
void finishJob(){
  if(wetRunning){
    if(wetVisit<WET_PURGE_VISIT&&wetVisit%9)wetWellsDone++;
    if(wetVisit==WET_PARK_VISIT){
      wetRunning=false;
      message=String(wetStop?"Dispense stopped":"Plate finished")+" · "+String(wetWellsDone)+"/96 wells · Z100 · motors released";
      busy=false;logMessage(message);return;
    }
    wetVisit=wetStop?WET_PARK_VISIT:wetVisit+1;
    nextWetVisit();return;
  }
  if(dryRunning){
    if(!dryStop&&++dryVisit<DRY_VISITS){nextDryVisit();return;}
    dryRunning=false;
    beginJob(dryStop?"Dry run stopped at travel Z":"Dry run 96 wells finished",{"G90","G1 Z"+String(points[6].z,3)+" F300","M400","M114","M400","M84"});
    return;
  }
  if(job==LIMIT_MONITOR){busy=false;return;}
  if(job==HOLD_TEST||job==MOTION_TEST)logMessage(job+": "+String(holdSamples)+" readings, "+String(holdTriggers)+" triggered; motor release acknowledged");
  if(job=="Checking Marlin replies")ready=true;
  if(job=="Home X/Y"||job=="Home all")xyHomed=true;
  if(job=="Home Z"||job=="Home all")zHomed=true;
  if(job=="Home syringe"||job=="Home all"){
    // A successful command must also report the empty home coordinate.
    aHomed=havePosition&&std::fabs(position.a)<0.01f;
    if(!aHomed){message="Syringe did not report A=0; re-home before teaching";busy=false;return;}
  }
  if(job=="Capture syringe 300 uL"){
    if(!aHomed||!validSyringeFull(syringeFullFromReference(candidate.a))){
      message="Invalid 300 uL position; inferred full stroke must be within 100 mm";busy=false;return;
    }
    float old=syringeFull,oldReference=syringeReferenceUl;
    syringeFull=syringeFullFromReference(candidate.a);syringeReferenceUl=SYRINGE_REFERENCE_UL;
    if(!persist()){syringeFull=old;syringeReferenceUl=oldReference;message="Storage failed; syringe calibration was not saved";busy=false;return;}
  }
  if(captureIndex>=0){
    Position old=points[captureIndex];bool had=present[captureIndex],hadCheck=present[3];
    points[captureIndex]=candidate;present[captureIndex]=true;
    if(captureIndex<3)present[3]=false; // Recheck H12 after changing any grid anchor.
    if(!persist()){
      points[captureIndex]=old;present[captureIndex]=had;present[3]=hadCheck;
      message="Storage failed; capture was not saved";busy=false;return;
    }
  }
  message=ready?job+" complete · motors released":"Waiting for connection";
  if(captureIndex>=0)message="Saved "+String(pointNames[captureIndex])+" · motors released";
  busy=false;logMessage(message);
}
void receiveLine(const char *line){
  if(!*line)return;
  logMessage(String("RX ")+line);
  if(strncmp(line,"Error:",6)==0||strncmp(line,"Resend:",7)==0||strncmp(line,"!!",2)==0){fail(line);return;}
  if(!awaiting)return;
  if(commands[commandIndex]=="M115"){
    if(strstr(line,"FIRMWARE_NAME:Marlin")&&strstr(line,"Liquid Handler"))identitySeen=true;
    if(strncmp(line,"Cap:",4)==0)capabilities++;
  }
  if(commands[commandIndex]=="M114" && strncmp(line,"X:",2)==0){
    Position p;if(!parsePosition(line,p)||!inside(p)){fail("Invalid position reply");return;}
    position=p;havePosition=true;positionSeen=true;candidate=p;
  }
  if(commands[commandIndex]=="M119"){
    if(strcmp(line,"a_min: open")==0)pendingALimit=0;
    else if(strcmp(line,"a_min: TRIGGERED")==0)pendingALimit=1;
  }
  if(strcmp(line,"ok")==0||strncmp(line,"ok ",3)==0){
    if(commands[commandIndex]=="M119"){
      if(pendingALimit<0){fail("Missing A limit-switch reply");return;}
      aLimitTriggered=pendingALimit==1;aLimitKnown=true;aLimitAt=millis();aLimitSamples++;
      if(samplingCommand()){
        holdSamples++;if(aLimitTriggered)holdTriggers++;
        logMessage(String(job==HOLD_TEST?"HOLD_SAMPLE":"MOTION_SAMPLE")+" ms="+String(millis()-holdStartedAt)+" A="+(aLimitTriggered?"TRIGGERED":"open"));
      }
    }
    if(commands[commandIndex]=="M114"&&!positionSeen){fail("Missing complete position reply");return;}
    if(commands[commandIndex]=="M115"&&(!identitySeen||capabilities<10)){fail("Incomplete firmware identification");return;}
    if(job==HOLD_TEST&&commands[commandIndex]=="M17")holdStartedAt=millis();
    if(job==MOTION_TEST&&commandIndex==8)holdStartedAt=millis();
    awaiting=false;
    // Keep this one read-only command active for ten seconds after M17 / G1.
    // The queue remains busy; no other jobs or motor releases can interleave.
    if(!(samplingCommand()&&millis()-holdStartedAt<10000))commandIndex++;
    if(commandIndex==commandCount)finishJob();
  }
}
void serviceUSB(){
  usb.Task();
  if(ender.connected()!=connected){
    connected=ender.connected();mountedAt=millis();inputLength=0;droppingLine=false;
    ready=busy=awaiting=havePosition=xyHomed=zHomed=aHomed=false;dryRunning=wetRunning=false;
    aLimitKnown=false;
    message=connected?"CH340 detected · waiting for Marlin":"Ender disconnected";
    logMessage(message);
  }
  if(!connected)return;
  for(unsigned packet=0;packet<16;packet++){
    uint8_t data[64];uint16_t n=sizeof(data);uint8_t rc=ender.read(data,n);
    if(rc==hrNAK)break;
    if(rc){fail("USB receive error "+String(rc));return;}
    if(!n)break;lastRX=millis();
    for(unsigned i=0;i<n;i++){
      char c=data[i];if(c=='\r')continue;
      if(c=='\n'){
        if(droppingLine){droppingLine=false;inputLength=0;fail("Overlong reply");return;}
        inputLine[inputLength]=0;receiveLine(inputLine);inputLength=0;
      }else if(inputLength<sizeof(inputLine)-1)inputLine[inputLength++]=c;
      else droppingLine=true;
    }
  }
  if(!busy&&!ready&&message=="CH340 detected · waiting for Marlin"&&millis()-mountedAt>2500&&millis()-lastRX>200)startCheck();
  if(awaiting){
    uint32_t limit=(wetRunning||commands[commandIndex].startsWith("G28"))?180000:(dryRunning||job.startsWith("Dry run")||job.startsWith("Home ")||job=="Jog syringe")?60000:10000;
    if(millis()-sentAt>limit)fail("No acknowledgement for "+commands[commandIndex]);
  }else if(busy&&millis()-lastRX>15){
    if(samplingCommand()){
      if(millis()-holdLastPoll<LIMIT_POLL_MS)return;
      holdLastPoll=millis();
    }
    String body="N"+String(lineNumber)+" "+commands[commandIndex];uint8_t checksum=0;
    for(unsigned i=0;i<body.length();i++)checksum^=body[i];
    String wire=body+"*"+String(checksum)+"\n";
    logMessage("TX "+commands[commandIndex]);
    if(ender.write(wire.c_str())){fail("USB send failed");return;}
    lineNumber++;positionSeen=false;pendingALimit=-1;awaiting=true;sentAt=millis();
  }
}
void error(int code,const String &why){JsonDocument d;d["error"]=why;String s;serializeJson(d,s);web.send(code,"application/json",s);}
bool readBody(JsonDocument &d){if(web.arg("plain").length()>1024||deserializeJson(d,web.arg("plain"))){error(400,"Invalid request");return false;}return true;}
void stateResponse(){
  JsonDocument d;calibration(d);d.remove("wells");d["ready"]=ready;d["busy"]=busy;d["message"]=message;
  d["dryRunning"]=dryRunning;d["dryVisit"]=dryVisit;d["dryStopRequested"]=dryStop;
  d["wetRunning"]=wetRunning;d["wetStopRequested"]=wetStop;
  d["wetWellsDone"]=wetWellsDone;d["wetVisit"]=wetVisit;d["parkZ"]=WET_PARK_Z;
  bool wetCalibrated=true;for(bool p:present)if(!p)wetCalibrated=false;
  d["wetCalibrationValid"]=wetCalibrated&&wetRunValid(points,syringeFull,position);
  d["wetTrialCalibrationValid"]=wetCalibrated&&wetRunValid(points,syringeFull,position,true);
  d["aHomed"]=aHomed;
  d["xyHomed"]=xyHomed;d["zHomed"]=zHomed;d["saved"]=saved;d["log"]=logText;
  d["aLimit"]=aLimitFresh()?(aLimitTriggered?"TRIGGERED":"open"):"unknown";
  d["aLimitFresh"]=aLimitFresh();d["aLimitSamples"]=aLimitSamples;
  if(aLimitKnown)d["aLimitAgeMs"]=millis()-aLimitAt;
  if(havePosition)serializePosition(d["position"].to<JsonObject>(),position);
  if(!present[0]||!present[1]||!present[2])d["geometry"]="Capture A1, A12, and H1.";
  else if(!geometryOK())d["geometry"]="Check the taught points: expected 99 mm across, 63 mm down, and square axes.";
  else if(!present[3])d["geometry"]="Grid calculated. Capture H12 independently to verify it.";
  else d["geometry"]="H12 check error: "+String(checkError(),2)+" mm. "+(plateVerified()?"Plate verified.":"Above 1 mm; check and recapture the points.");
  d["heights"]=heightsOK()?"Heights saved. Confirm the travel path clears all obstacles.":"Capture reservoir, dispense, and travel heights. Travel Z must be higher than the working heights.";
  String s;serializeJson(d,s);web.sendHeader("Cache-Control","no-store");web.send(200,"application/json",s);
}
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
void loop(){
  if(hostOK)serviceUSB();
  M5.update();
  // Redraw during long command waits too (e.g. homing), but outside reply bursts.
  if(millis()-lastDraw>50&&millis()-lastRX>30&&(!awaiting||millis()-sentAt>250)){
    lastDraw=millis();draw();
  }
  // Serve browser only outside reply bursts, avoiding USB starvation.
  if((!awaiting||millis()-sentAt>250) && millis()-lastRX>30){
    if(millis()-lastWeb>30){lastWeb=millis();web.handleClient();}
  }
  // Continuous read-only monitoring, serialized with all existing jobs.
  // M119 does not energize motors; never inject releases into panel-driven motion.
  if(ready&&!busy&&millis()-lastLimitPoll>=LIMIT_POLL_MS&&millis()-lastRX>40){
    lastLimitPoll=millis();beginJob(LIMIT_MONITOR,{"M119"});
  }
}

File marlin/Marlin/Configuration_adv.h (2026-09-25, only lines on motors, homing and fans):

#define E0_AUTO_FAN_PIN -1
#define E1_AUTO_FAN_PIN -1
#define E2_AUTO_FAN_PIN -1
#define E3_AUTO_FAN_PIN -1
#define E4_AUTO_FAN_PIN -1
#define E5_AUTO_FAN_PIN -1
#define E6_AUTO_FAN_PIN -1
#define E7_AUTO_FAN_PIN -1
#define CHAMBER_AUTO_FAN_PIN -1
#define COOLER_AUTO_FAN_PIN -1
#define HOMING_BUMP_MM      { 5, 5, 2, 2 }       // (linear=mm, rotational=°) Backoff from endstops after first bump
#define HOMING_BUMP_DIVISOR { 2, 2, 4, 4 }       // Re-Bump Speed Divisor (Divides the Homing Feedrate)
#define MICROSTEP_MODES { 16, 16, 16, 16, 16, 16 } // :[ 1, 2, 4, 8, 16 ]

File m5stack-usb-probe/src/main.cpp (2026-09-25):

#include <Arduino.h>
#include <SPI.h>
#include <M5Stack.h>
#include <stdarg.h>
#include <M5_Max3421E_Usb.h>

SPIClass &sharedSPI = M5.Lcd.getSPIinstance();
M5_USBH_Host usb(&sharedSPI, 18, 23, 19, 5, 35);
Adafruit_USBH_CDC ender;
bool attached = false;
bool hostReady = false;
uint32_t mountedAt = 0;
uint32_t lastReport = 0;
unsigned sent = 0;
char screenLines[9][27] = {};
unsigned column = 0;
bool screenDirty = true;
uint32_t lastDraw = 0, received = 0;

void screenText(const char *text, size_t length) {
  for (size_t i = 0; i < length; ++i) {
    char c = text[i];
    if (c == '\r') continue;
    if (c == '\n' || column == 26) {
      memmove(screenLines[0], screenLines[1], 8 * sizeof(screenLines[0]));
      memset(screenLines[8], 0, sizeof(screenLines[8]));
      column = 0;
      if (c == '\n') continue;
    }
    screenLines[8][column++] = (c >= 32 && c <= 126) ? c : '.';
  }
  screenDirty = true;
}
void logf(const char *format, ...) {
  char text[192];
  va_list args;
  va_start(args, format);
  vsnprintf(text, sizeof(text), format, args);
  va_end(args);
  Serial.print(text);
  screenText(text, strlen(text));
}
void drawScreen() {
  M5.Lcd.setTextSize(2);
  M5.Lcd.setTextColor(hostReady ? GREEN : YELLOW, BLACK);
  M5.Lcd.fillRect(0, 26, 320, 18, BLACK);
  M5.Lcd.setCursor(4, 26);
  M5.Lcd.print(!hostReady ? "USB HOST INIT FAILED" : attached ? "ENDER SERIAL CONNECTED" : "Waiting for USB device");
  if (screenDirty) {
    M5.Lcd.fillRect(0, 52, 320, 148, BLACK);
    M5.Lcd.setTextColor(WHITE, BLACK);
    for (unsigned i = 0; i < 9; ++i) {
      M5.Lcd.setCursor(4, 52 + i * 16);
      M5.Lcd.print(screenLines[i]);
    }
  }
  screenDirty = false;
  M5.Lcd.fillRect(0, 205, 320, 35, BLACK);
  M5.Lcd.setTextColor(CYAN, BLACK);
  M5.Lcd.setCursor(4, 205);
  M5.Lcd.printf("Up %lus  RX %lu", (unsigned long)(millis()/1000), (unsigned long)received);
  M5.Lcd.setCursor(4, 223);
  M5.Lcd.print("A: restart probe");
}
const char *queries[] = {"M115\n", "M114\n", "M119\n"};

void tuh_mount_cb(uint8_t address) {
  uint16_t vid, pid;
  tuh_vid_pid_get(address, &vid, &pid);
  logf("USB attached: address=%u VID:PID=%04x:%04x\n", address, vid, pid);
}
void tuh_umount_cb(uint8_t address) {
  logf("USB removed: address=%u\n", address);
}
void tuh_cdc_mount_cb(uint8_t idx) {
  attached = ender.mount(idx);
  mountedAt = millis();
  sent = 0;
  logf("Serial mount: success=%d baud=%lu\n", attached, (unsigned long)ender.baud());
}
void tuh_cdc_umount_cb(uint8_t idx) {
  attached = false;
  ender.umount(idx);
  logf("Serial disconnected\n");
}
void tuh_hid_report_received_cb(uint8_t, uint8_t, uint8_t const*, uint16_t) {}
void tuh_hid_report_sent_cb(uint8_t, uint8_t, uint8_t const*, uint16_t) {}

void setup() {
  Serial.begin(115200);
  pinMode(5, OUTPUT); digitalWrite(5, HIGH);
  M5.begin(true, false, false, false);
  M5.Lcd.setRotation(1);
  M5.Lcd.fillScreen(BLACK);
  M5.Lcd.setTextSize(2);
  M5.Lcd.setTextColor(CYAN, BLACK);
  M5.Lcd.setCursor(4, 4);
  M5.Lcd.print("Core Basic: Ender USB");
  M5.Lcd.setCursor(4, 26);
  M5.Lcd.print("Checking USB module...");
  // Keep SD inactive. LCD and USB use the same SPI object/transaction lock.
  pinMode(14, OUTPUT); digitalWrite(14, HIGH);
  pinMode(4, OUTPUT); digitalWrite(4, HIGH);
  sharedSPI.begin(18, 19, 23, 5);
  pinMode(5, OUTPUT); digitalWrite(5, HIGH);
  for (uint32_t hz : {1000000UL, 4000000UL, 8000000UL, 26000000UL}) {
    sharedSPI.beginTransaction(SPISettings(hz, MSBFIRST, SPI_MODE0));
    digitalWrite(5, LOW); sharedSPI.transfer(0x8a); sharedSPI.transfer(0x10); digitalWrite(5, HIGH);
    digitalWrite(5, LOW); sharedSPI.transfer(0x90); uint8_t rev = sharedSPI.transfer(0); digitalWrite(5, HIGH);
    sharedSPI.endTransaction();
    logf("SPI %lu MHz: rev 0x%02x\n", (unsigned long)(hz/1000000), rev);
  }
  ender.begin(250000);
  logf("Read-only probe: 250000 bps\n");
  hostReady = usb.begin(1);
  logf("MAX3421E init: %s\n", hostReady ? "OK" : "FAILED");

}
void loop() {
  M5.update();
  if (M5.BtnA.wasPressed()) ESP.restart();
  if (millis() - lastDraw >= 1000) {
    lastDraw = millis();
    drawScreen();
  }
  if (!hostReady) { delay(10); return; }

  usb.task(0);
  if (attached && ender.available()) {
    uint8_t buf[64];
    size_t n = ender.read(buf, sizeof(buf));
    Serial.write(buf, n);
    received += n;
    screenText(reinterpret_cast<const char *>(buf), n);
  }
  if (attached && sent < 3 && millis() - mountedAt > 3000 + sent * 3000) {
    logf("TX: %s", queries[sent]);
    ender.print(queries[sent++]);
    ender.flush();
  }
  if (millis() - lastReport > 10000) {
    lastReport = millis();
    logf("Probe: serial=%s baud=%lu queries=%u\n", attached ? "mounted" : "waiting", (unsigned long)ender.baud(), sent);
  }
  delay(1);
}

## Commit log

2026-09-25 Initial liquid handler firmware, controller, and CAD project
    [Configuration.h, Configuration_adv.h, LH_deck.step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]
2026-09-28 Add calibrated plate dispensing, SD-card job, and reservoir CAD variants
    [LH_deck.step, LH_deck.stl, LH_deck_assembly.step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]
2026-09-29 new lead screw pitch
    [Configuration.h]
2026-09-29 Initialize README with project overview and BOM
    Added project description and advantages for the Ender 3 liquid handler.
2026-10-01 Add reference link to Ender 3 modification article
    Added a reference link to an article about modifying the Ender 3 printer.

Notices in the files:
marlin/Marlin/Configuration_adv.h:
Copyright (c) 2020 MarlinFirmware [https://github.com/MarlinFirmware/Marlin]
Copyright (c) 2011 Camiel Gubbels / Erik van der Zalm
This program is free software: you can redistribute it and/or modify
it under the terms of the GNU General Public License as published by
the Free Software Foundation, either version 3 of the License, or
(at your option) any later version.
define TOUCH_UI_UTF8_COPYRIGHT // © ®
